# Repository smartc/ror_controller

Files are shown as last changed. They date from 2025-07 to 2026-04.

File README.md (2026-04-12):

# ESP32-S3 Roll-Off Roof Controller (v3)

ASCOM Alpaca compatible roll-off roof controller for remote observatory automation, built on ESP32-S3 with MQTT integration, weather safety interlock, and a browser-based control interface.





---

## SAFETY WARNING

**Relays on this board carry low-voltage control signals only.** They trigger external contactors -- never connect motors, inverters, or other high-current loads directly to the relay outputs. Use appropriately rated external contactors for all high-power switching.

---

## Features

### Roof Control
- Non-blocking state machine sequences relay operations without interrupting WiFi/MQTT
- Open, close, and stop via ASCOM, MQTT, or web interface
- Limit switch detection with configurable trigger state and swap option
- Two independent configurable timeouts: limit switch response (default 5s) and total movement (default 90s)

### Safety Interlocks
- **Park sensor**: blocks roof movement when telescope is unparked. Supports physical GPIO, UDP network sensors, or both (AND logic)
- **Weather/sky safety**: receives UDP broadcasts from safety sensor devices; blocks roof opening when any enabled sensor reports unsafe conditions. Fail-safe: an enabled sensor that goes offline is treated as unsafe
- **Auto-close**: optionally closes the roof automatically when weather becomes unsafe (requires telescope parked)
- All safety interlocks have bypass toggles accessible from both the Setup and Roof Control pages

### Inverter Control (v3 hardware)
- K1: 12V power relay (triggers external contactor)
- K3: Soft-power button relay (500ms pulse)
- AC power detection via optocoupler distinguishes relay state from actual inverter output
- Manual controls available from Roof Control page

### Web Interface
- Dark theme, responsive layout, 2-second live status polling
- Consistent navigation on all pages: Home, Roof Control, Setup, WiFi Config, Console, Update
- **Console page**: live ring-buffer debug log (50 entries), accessible remotely without serial monitor
- Park sensor and safety sensor management: per-sensor enable, bypass, and remove
- OTA firmware updates via ElegantOTA (auto-reboot after upload)

### MQTT / Home Assistant
- Publishes status every 30 seconds and on state change
- Accepts open/close/stop commands
- LWT availability topic
- Status payload includes weather safety state and safety bypass flag

### GPS / NTP / RTC
- Optional GPS module for time sync (configurable pins)
- DS3231 RTC backup (I2C)
- NTP server mode: serves time to local network devices
- PPS signal support for sub-second NTP accuracy
- Configurable timezone offset and DST

---

## Hardware (v3)

**Microcontroller**: ESP32-S3 44-pin  
**Power**: 12V DC input, onboard 5V regulator

### GPIO Assignments

| Pin | Function |
|-----|---|
| GPIO4 | K1 - Inverter power relay |
| GPIO5 | K2 - Roof button relay |
| GPIO6 | K3 - Inverter soft-power relay |
| GPIO7 | AC power detection (optocoupler) |
| GPIO8 | I2C SDA (RTC) |
| GPIO9 | I2C SCL (RTC) |
| GPIO35 | Open limit switch |
| GPIO36 | Closed limit switch |
| GPIO37 | Rain sensor (RG9) |
| GPIO38-41 | Snow sensor (digital + RS485) |
| GPIO42 | Physical park sensor |

GPS pins are configurable via the web interface (default TX: GPIO14).

---

## Installation

### Requirements

- Arduino IDE 2.0+
- Board: ESP32-S3 Dev Module
- Libraries (via Library Manager): ArduinoJson 6.x, PubSubClient, ElegantOTA

### Board Settings

| Setting | Value |
|---|---|
| USB CDC On Boot | Enabled |
| Flash Size | 4MB |
| Partition Scheme | Default 4MB with SPIFFS |
| Upload Speed | 921600 |
| USB Mode | Hardware CDC and JTAG |

### First Boot

1. Device starts in AP mode: SSID `RoofController`, password `RoofController`
2. Connect and open `http://192.168.4.1`
3. Enter WiFi credentials under WiFi Config
4. Device reboots and connects to your network

---

## Configuration

All settings are saved to NVS (survives reboots) and configurable via the web interface.

**Setup page** (`/setup`): pin assignments, trigger states, timeout values, MQTT broker, park sensor type, safety sensor enable/bypass, GPS/NTP settings, timezone

**WiFi Config** (`/wificonfig`): SSID and password

**Roof Control** (`/control`): park sensor bypass and safety sensor bypass toggles accessible here for quick override without navigating to setup

---

## MQTT

**Default topic prefix**: `observatory/roof`

| Topic | Direction | Description |
|---|---|---|
| `<prefix>/status` | Publish | JSON status (30s interval + on change) |
| `<prefix>/command` | Subscribe | `{"command":"open\|close\|stop"}` |
| `<prefix>/availability` | Publish | `online` / `offline` (LWT) |

### Status payload

```json
{
  "status": "Closed",
  "telescope_parked": true,
  "bypass_enabled": false,
  "weather_safe": true,
  "safety_bypass": false,
  "inverter_relay_state": false,
  "inverter_ac_power_state": false,
  "limit_open": false,
  "limit_closed": true,
  "device_id": "ESP32-XXXXXX",
  "ip_address": "192.168.1.100",
  "version": "3.3.0"
}
```

### Home Assistant example

```yaml
mqtt:
  cover:
    - name: "Observatory Roof"
      command_topic: "observatory/roof/command"
      state_topic: "observatory/roof/status"
      payload_open: '{"command":"open"}'
      payload_close: '{"command":"close"}'
      payload_stop: '{"command":"stop"}'
      value_template: "{{ value_json.status }}"
      state_open: "Open"
      state_closed: "Closed"
      availability_topic: "observatory/roof/availability"

  binary_sensor:
    - name: "Weather Safe"
      state_topic: "observatory/roof/status"
      value_template: "{{ value_json.weather_safe }}"
      payload_on: true
      payload_off: false
```

---

## ASCOM Alpaca

- Discovery: UDP port 32227, responds to `alpacadiscovery1`
- API base: `http://<device-ip>:11111/api/v1/dome/0/`
- Device type: Dome (RollOffRoof)

| Method | Description |
|---|---|
| `GET shutterstatus` | 0=Open, 1=Closed, 2=Opening, 3=Closing, 4=Error |
| `PUT openshutter` | Open roof (checks park + weather safety) |
| `PUT closeshutter` | Close roof |
| `PUT abortslew` | Stop movement |
| `GET athome` | True when closed |
| `GET atpark` | True when open |

---

## Web API

| Endpoint | Method | Description |
|---|---|---|
| `/` | GET | Home / status page |
| `/control` | GET | Roof control page |
| `/setup` | GET/POST | Configuration page |
| `/console` | GET | Debug log viewer |
| `/console.json` | GET | Raw log JSON |
| `/api/status` | GET | Live status JSON |
| `/open` | POST | Open roof |
| `/close` | POST | Close roof |
| `/stop` | POST | Stop movement |
| `/toggle_bypass` | POST | Toggle park sensor bypass |
| `/toggle_safety_bypass` | POST | Toggle safety sensor bypass |
| `/safety_sensor_enabled` | POST | Enable/disable a safety sensor |
| `/safety_sensor_bypass` | POST | Bypass a safety sensor |
| `/safety_sensor_remove` | POST | Remove a safety sensor |
| `/inverter_toggle` | POST | Toggle K1 power relay |
| `/inverter_button` | POST | K3 soft-power button press |
| `/update` | GET | OTA firmware update |
| `/restart` | POST | Reboot device |

---

## PCB Files

The `PCB Files/` directory contains v3.0 manufacturing files: schematic, layout, Gerbers, BOM, pick-and-place, and 3D model. Designed for JLCPCB, PCBWay, or equivalent.

---

## Changelog

### v3.3.0 (2026-04-12)
- Safety sensor integration: weather/sky condition interlock via UDP broadcasts
- Auto-close on unsafe weather (configurable, requires telescope parked)
- Safety sensor bypass controls on Setup and Roof Control pages
- Weather safe status and safety bypass state added to MQTT and `/api/status`
- Unified navigation bar across all pages with Console link
- Web-based debug console at `/console` (ring buffer, no serial monitor needed)
- Toggle switches replace checkboxes in safety sensor table
- Per-sensor remove and remove-all for both park and safety sensors
- Park sensor type saves immediately on selection (no Apply button)
- ElegantOTA auto-reboot fix
- HTML entity encoding for all non-ASCII characters

### v3.2.0 (2026-01-18)
- GPS/RTC/NTP support with PPS signal for sub-second accuracy
- DS3231 RTC backup with I2C detection
- NTP server mode for local network devices
- Timezone and DST configuration

### v3.0.0 (2026-01-11)
- Migrated to ESP32-S3 (44-pin)
- Triple relay system (K1, K2, K3)
- AC power detection via optocoupler
- Snow sensor input (digital + RS485)
- Dual inverter state tracking (relay vs AC power)
- Non-blocking roof state machine
- Dual movement timeout system

### v2.1.0
- Initial release: ESP32, ASCOM Alpaca, MQTT, UDP park sensors

---

## License

MIT License. See [LICENSE](LICENSE) for details.

**Author**: Corey Smart

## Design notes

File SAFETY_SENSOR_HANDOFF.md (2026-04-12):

# ROR Controller – Safety Sensor Integration Handoff

## Context

The SkyConditions_90640 device (ESP32-S3 ASCOM sky conditions sensor, separate project at
`../SkyConditions_90640`) has been updated to broadcast a UDP safety packet on the local
subnet using the Dark Dragon Astronomy park-sensor protocol. This document describes the
changes needed to the ROR controller to receive and act on those broadcasts.

The design should also accommodate **future distributed safety sensors** of the same type
(e.g. a standalone cloud sensor, an all-sky camera, a wind sensor) — any device that can
broadcast a `SafetySensor` UDP packet on the same port should be automatically discovered
and incorporated into the safety decision, using the same per-sensor enable/bypass model
that already exists for park sensors.

---

## What the SkyConditions device broadcasts

**UDP port:** 23435 (same port the ROR controller already listens on for park sensors)

**Interval:** Every 30 seconds by default; immediately on any wet ↔ dry state change.

**Packet format (JSON):**
```json
{
  "serialNumber": "a4cf1234abcd",
  "deviceType":   "SafetySensor",
  "name":         "Observatory Safety Sensor",
  "isSafe":       true,
  "rainState":    "dry",
  "ambTemp":      12.5
}
```

Key differences from park sensor packets:
- `deviceType` is `"SafetySensor"` (park sensors use `"ScopeParkSensor"` or similar)
- Safety state field is `"isSafe"` (park sensors use `"isSafeToMove"`)
- No `pitch` or `roll` fields
- Extra fields: `rainState` (`"wet"` or `"dry"`), `ambTemp` (°C, or JSON `null` before first sensor read)
- `serialNumber` is the device MAC address (hex, no colons) — stable and unique per device

**Current ROR behaviour:** The existing `processParkSensorMessage()` in `park_sensor_udp.cpp`
checks for the presence of `isSafeToMove` and silently drops any packet missing it, so
SafetySensor packets are already harmlessly ignored. Nothing is broken — this is purely additive.

---

## Changes required

### 1. Parse SafetySensor packets in `park_sensor_udp.cpp`

Add handling alongside the existing park sensor parser. When a packet arrives with
`deviceType == "SafetySensor"`:
- Read `isSafe` (bool) instead of `isSafeToMove`
- Store in a dedicated map keyed by `serialNumber`, separate from `discoveredSensors`
- Track `lastSeen` timestamp; mark offline after 90 seconds (3× the default broadcast interval)
- Log new discoveries and state changes; suppress repeated identical-state packets

Suggested data structure — mirrors the park sensor pattern closely for consistency:

```cpp
struct SafetySensor {
  String        serialNumber;
  String        name;
  String        ipAddress;
  bool          isSafe;
  float         ambTemp;         // NaN if JSON null was received
  unsigned long lastSeen;
  bool          online;          // false if timed out
  bool          enabled;         // user has opted this sensor into the safety decision
  bool          bypassEnabled;   // per-sensor bypass (excluded from safety check)
};

extern std::map<String, SafetySensor> discoveredSafetySensors;
```

### 2. Per-sensor enable and bypass — mirroring park sensor model

Each discovered SafetySensor should support:
- **Enabled** — user explicitly opts the sensor into the safety interlock. Newly discovered
  sensors default to **disabled** (discovered but not yet trusted) so an unexpected device
  on the network cannot silently gate the roof.
- **Bypass** — temporarily excludes an individual sensor from the safety decision without
  removing it. Useful for testing or known-bad sensor states.

Additionally, a **global safety sensor bypass** flag (`bypassSafetySensor`, default `false`)
overrides all sensors at once — the same pattern as `bypassParkSensor` for park sensors.
This is the testing / emergency override the user can toggle from the Setup or home page.

```cpp
bool bypassSafetySensor = false;   // global override — skips ALL safety sensor checks

// Returns true if weather is safe to open:
//   - global bypass enabled, OR
//   - no sensors are enabled, OR
//   - all enabled, non-bypassed, online sensors report isSafe=true
bool isWeatherSafe();
```

**`isWeatherSafe()` logic:**
```
if (bypassSafetySensor) return true;

hasActiveSensor = false
for each sensor in discoveredSafetySensors:
    if not sensor.enabled: continue
    if sensor.bypassEnabled: continue
    hasActiveSensor = true
    if not sensor.online: return false   // offline enabled sensor → fail-safe
    if not sensor.isSafe: return false

if not hasActiveSensor: return true      // no enabled sensors → don't block
return true
```

### 3. Gate roof OPENING on weather safety — do NOT gate closing

In `roof_controller.cpp`, the open safety check is around line 381.
Add a weather-safe interlock here:

```cpp
// === ROOF OPENING SAFETY CHECK ===
// Existing park sensor check ...
if (!bypassParkSensor && !telescopeParked) { return false; }

// NEW: weather safety — never open into rain/unsafe conditions
if (!isWeatherSafe()) {
    Debug.println("SAFETY CHECK FAILED: Weather unsafe");
    return false;
}
```

The closing check (around line 465) must **not** include a weather interlock —
rain is a reason to close, not a reason to refuse to close.

### 4. Auto-close on unsafe weather (optional, configurable)

Add a runtime-configurable NVS-backed setting:
- `weatherAutoClose` (bool, default: **false**)

When enabled, if `isWeatherSafe()` returns false AND the roof is currently open,
trigger a close command automatically.

**Critical safety requirement — check telescope park status before auto-closing:**

Auto-close must respect park sensor state including per-sensor bypass flags.
The existing `isTelescopeParked()` and `bypassParkSensor` already encapsulate this
correctly — use them directly:

```
if (weatherAutoClose && roofIsOpen && !isWeatherSafe()) {
    if (bypassParkSensor || isTelescopeParked()) {
        triggerClose("Auto-close: weather unsafe");
    } else {
        // Rain detected but telescope not confirmed parked — cannot safely close
        Debug.println("Auto-close SUPPRESSED: telescope not confirmed parked");
        // Surface a prominent warning in UI and MQTT
    }
}
```

Rain may be a cheaper problem than a smashed telescope. **Never auto-close if any
enabled, non-bypassed park sensor is offline, unparked, or in an unknown state.**

### 5. UI changes

**Setup page — new "Safety Sensors" section:**
- Table of all discovered SafetySensor devices (name, IP, serial, current state, last-seen)
- Per-sensor Enable checkbox and Bypass checkbox
- Global bypass toggle (`bypassSafetySensor`) with a clear warning label
- Toggle: "Auto-close on unsafe weather" (`weatherAutoClose`, default OFF)
  — display a warning that auto-close is suppressed if the telescope is not parked

**Home / status page:**
- Weather safety status badge: Safe / Unsafe / Bypassed / No sensor
- If auto-close is enabled and was suppressed by park sensor state, show a prominent alert

**MQTT:**
- Include `weather_safe: true/false` and `safety_bypass: true/false` in state payload
- Publish an event when auto-close is triggered or suppressed

---

## Extensibility — future safety sensors

The map-based design (`std::map<String, SafetySensor>`) naturally accommodates multiple
simultaneous devices. Any device on the same subnet that broadcasts a UDP packet with
`deviceType == "SafetySensor"` and `isSafe: true/false` will be automatically discovered
and appear in the UI for the user to enable. The `isWeatherSafe()` AND-logic then
incorporates all enabled, non-bypassed sensors.

Future sensor types that could use this same protocol:
- Standalone cloud/rain sensor
- Wind speed monitor
- All-sky camera safety output
- Generic "observatory is safe" relay device

No code changes are needed on the ROR controller to add new sensor instances — they
just need to broadcast the same JSON format.

---

## Relevant files to modify

| File | Changes needed |
|---|---|
| `park_sensor_udp.h/.cpp` | Add `SafetySensor` struct, map, parser, `isWeatherSafe()`, enable/bypass functions, NVS save/load |
| `roof_controller.cpp` | Weather interlock in open check (~line 381); auto-close logic in main loop |
| `roof_controller.h` | Expose `bypassSafetySensor`, `weatherAutoClose` |
| `config.h` | Add `SAFETY_SENSOR_TIMEOUT 90000` constant |
| `web_ui_handler.cpp` | POST handler for new settings |
| `html_templates.h` | Safety Sensors section on Setup page; status badge on home page |
| `mqtt_handler.cpp` | Publish `weather_safe` and `safety_bypass` in state payload |

Follow the existing NVS load/save pattern from `park_sensor_udp.cpp` for all new settings.

---

## Safety decision matrix

| Scenario | Open roof? | Close roof? | Auto-close? |
|---|---|---|---|
| Global safety bypass enabled | ✓ | ✓ | n/a |
| Weather safe, telescope parked | ✓ | ✓ | n/a |
| Weather safe, telescope unparked | ✗ | ✗ | n/a |
| Unsafe weather, telescope parked | ✗ | ✓ | ✓ if enabled |
| Unsafe weather, telescope unparked | ✗ | ✗ | ✗ suppressed |
| Unsafe weather, park sensor offline | ✗ | ✗ | ✗ suppressed |
| Unsafe weather, park sensor bypassed | ✗ | ✓ | ✓ if enabled |
| Safety sensor offline (was enabled) | ✗ | ✓ | ✓ if enabled + telescope parked |
| Safety sensor bypassed individually | ignored | ✓ | ✓ if enabled + telescope parked |
| No safety sensors enabled | ✓ | ✓ | n/a |

**Fail-safe principle:** an enabled safety sensor that goes offline should be treated as
unsafe for the purpose of the open interlock. The user can bypass it explicitly if they
know the sensor has failed and conditions are actually safe.

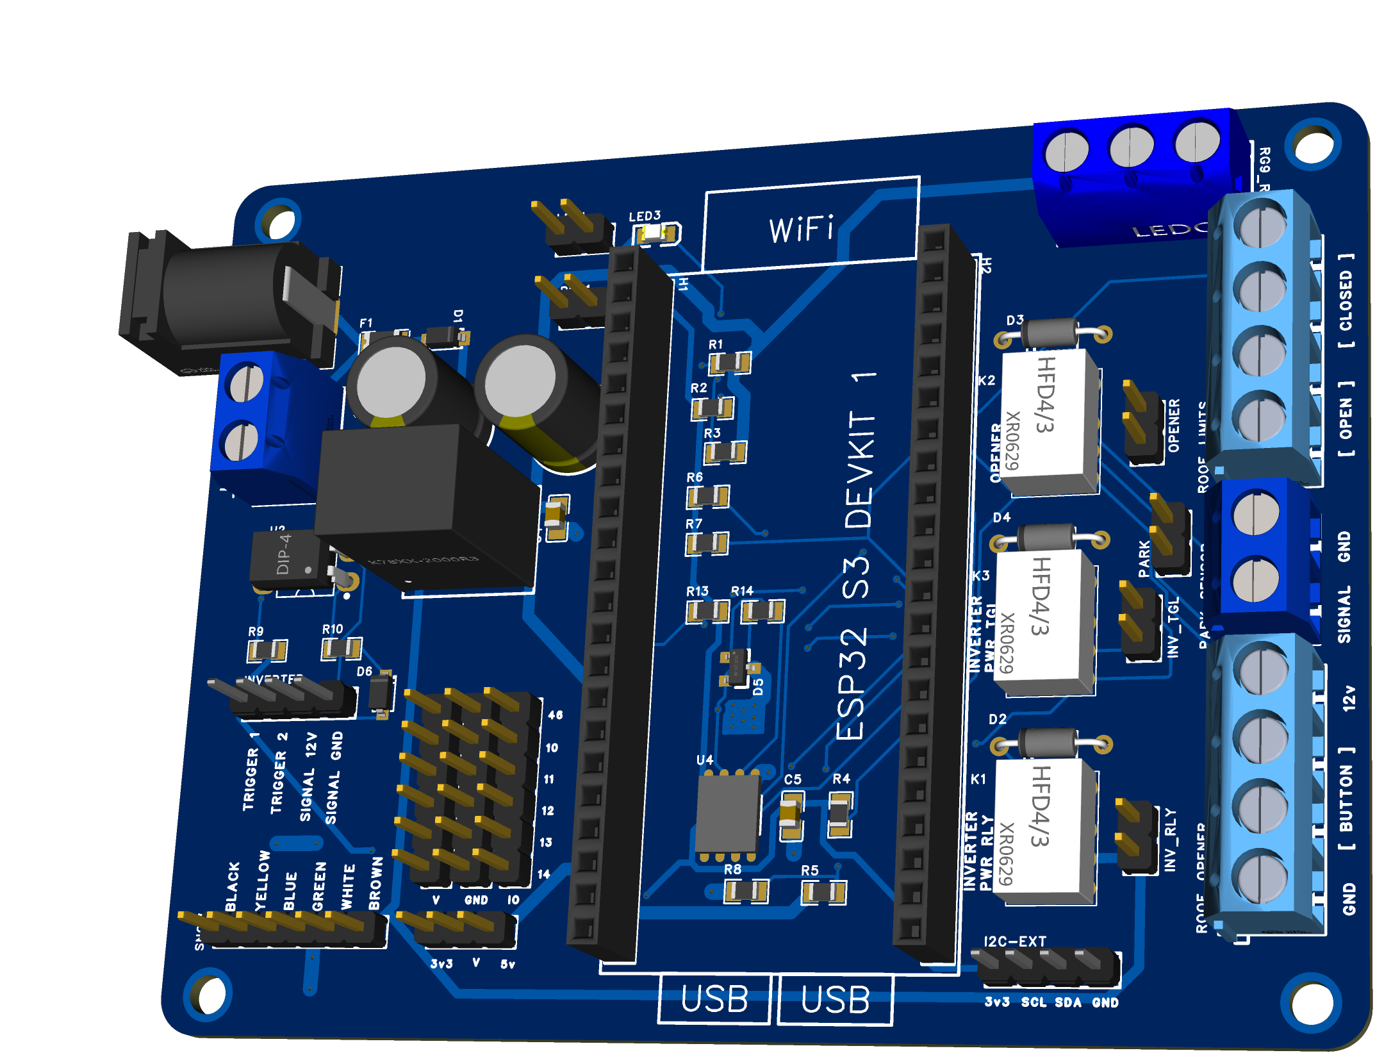
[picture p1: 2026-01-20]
PCB Files/3D_PCB_v3.1.png

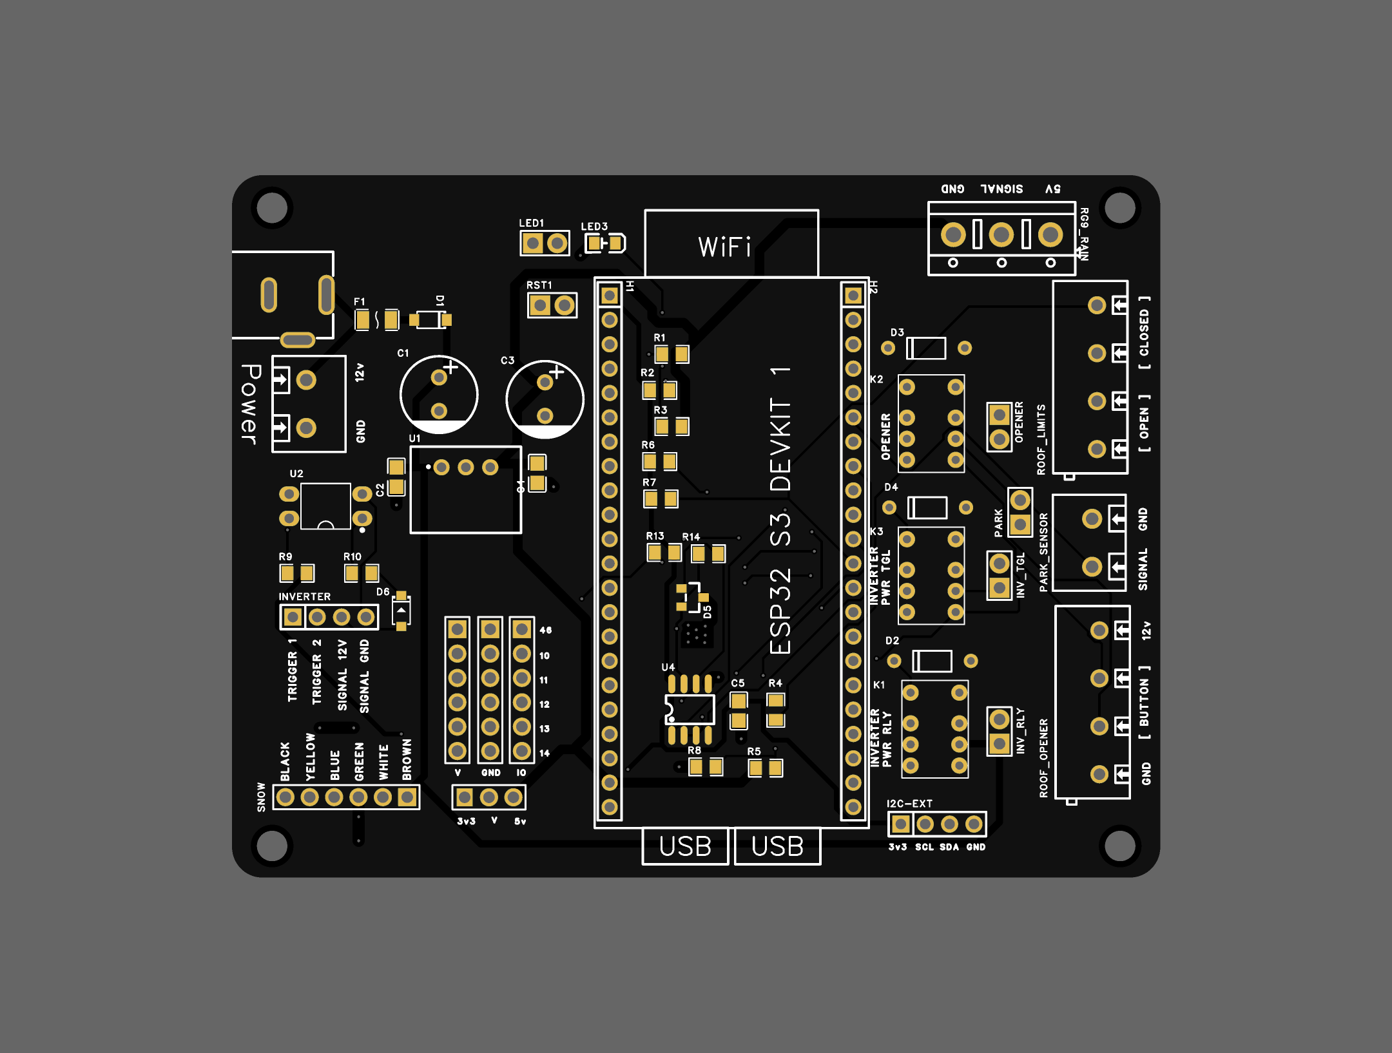
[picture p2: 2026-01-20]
PCB Files/2D_PCB_Top_v3.1.png

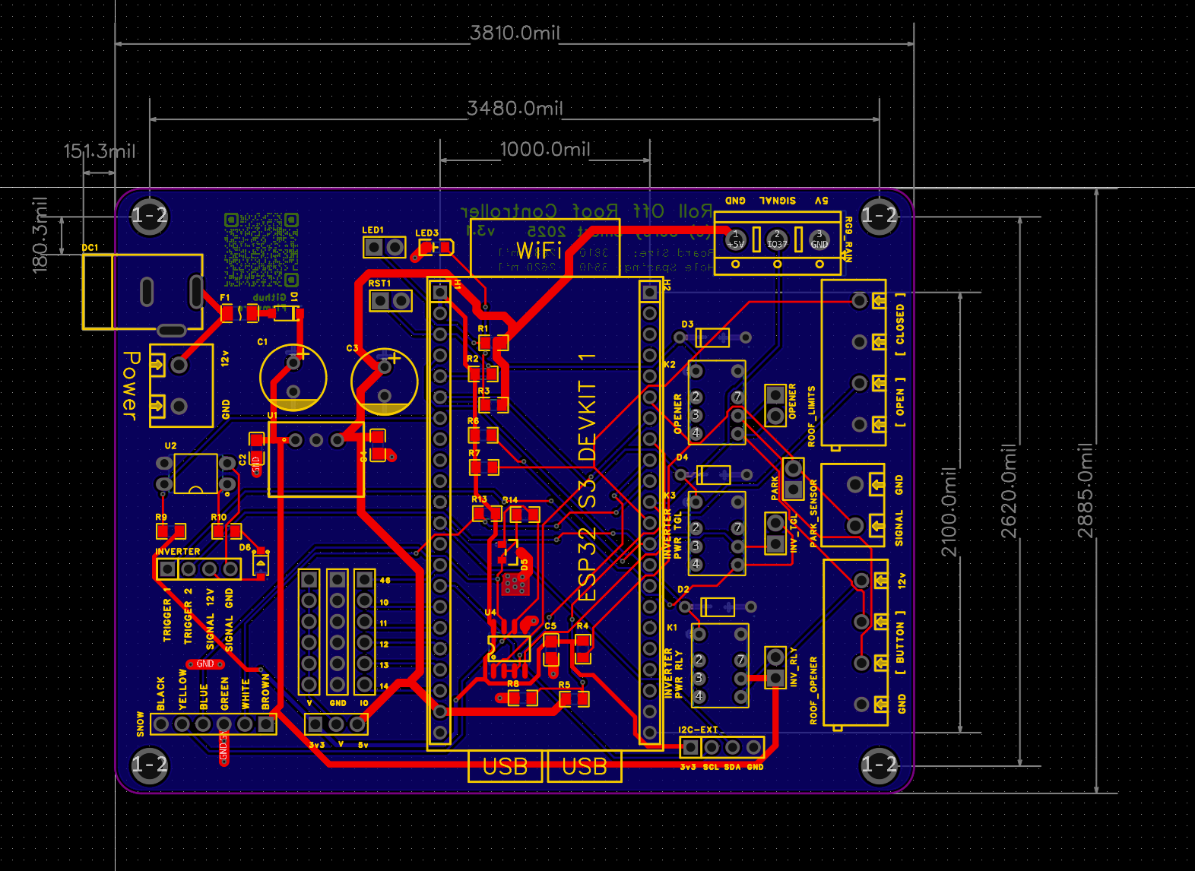
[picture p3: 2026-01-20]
PCB Files/PCB_Dimensions_v3.1.png

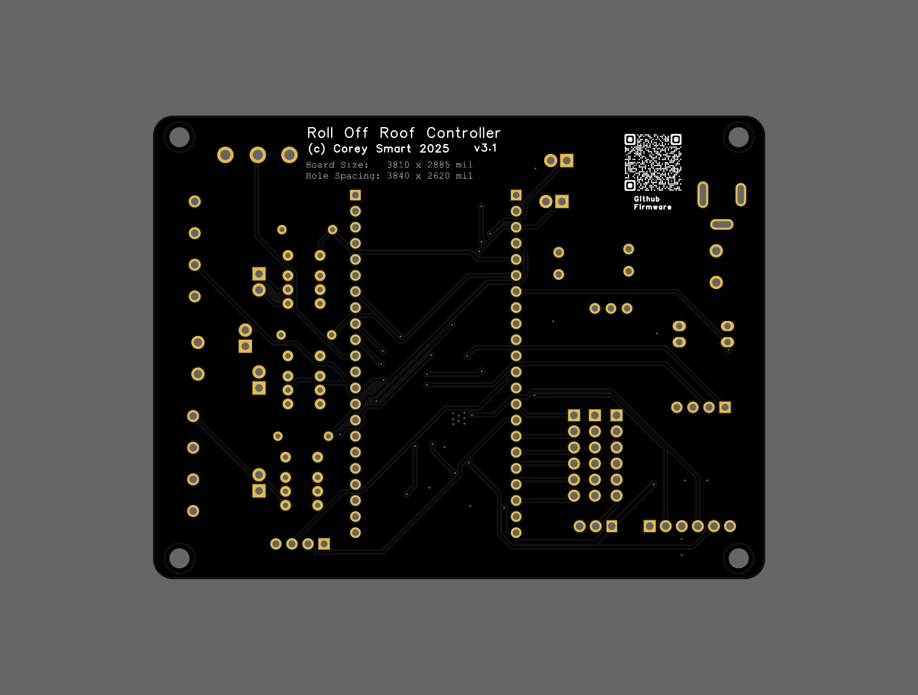
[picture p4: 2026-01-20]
PCB Files/2D_PCB_Bottom_v3.1.png

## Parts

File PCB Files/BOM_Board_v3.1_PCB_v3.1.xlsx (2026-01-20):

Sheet: bom模板
 |  |  |  | Bill of Materials | BOM_Board_v3.0_PCB_v3.0_2026-01-19
 |  |  |  | Project Title： | ESP32 ROR Controller (v3)
 |  |  |  | Variant:
 |  |  |  | Report Time： | 2026年1月19日 18:10:29
No. | Quantity | Comment | Designator | Footprint | Value | Manufacturer Part | Manufacturer | Supplier Part | Supplier | LCSC Price | Total
1 | 2 | 220uF | C1, C3 | CAP-TH_BD8.0-P3.50-D0.5-FD | 220uF | 220uF35V8x12KM | Econd(米朗电子) | C49304872 | LCSC |  | #VALUE!
2 | 1 | 10uF | C2 | C0805 | 10uF | C0805X106K010T | IHHEC(禾伸堂) | C340314 | LCSC |  | #VALUE!
3 | 1 | 22uF | C4 | C0805 | 22uF | CL21A226MAYNNNE | SAMSUNG(三星) | C602037 | LCSC |  | #VALUE!
4 | 1 | 100nF | C5 | C0805 | 100nF | C0805X104K101TB | IHHEC(禾伸堂) | C495959 | LCSC |  | #VALUE!
5 | 1 | DSK24 | D1 | SOD-123_L2.8-W1.8-LS3.7-RD |  | DSK24 | JUXING(钜兴) | C3033296 | LCSC |  | #VALUE!
6 | 3 | 1N4148 | D2, D3, D4 | DO-35_BD2.2-L4.0-D0.50_1N4148 |  | 1N4148 | LJ(朗捷) | C18195411 | LCSC |  | #VALUE!
7 | 1 | SM712 | D5 | SOT-23_L2.9-W1.3-P1.90-LS2.4-BR |  | SM712 | TDSEMIC(拓电半导体) | C46956321 | LCSC |  | #VALUE!
8 | 1 | 1N4148W | D6 | SOD-123_L2.7-W1.6-LS3.7-FD |  | 1N4148W | R+O(宏嘉诚) | C7420318 | LCSC |  | #VALUE!
9 | 1 | PJ-002A | DC1 | DC-IN-TH_PJ-002A |  | PJ-002A | CUI | C3096082 | LCSC |  | #VALUE!
10 | 1 | 0466002.NRHF | F1 | F1206 |  | 0466002.NRHF | Littelfuse(美国力特) | C3105 | LCSC |  | #VALUE!
11 | 2 | XY-PM254-1-22P-Z-8.5 | H1, H2 | HDR-TH_22P-P2.54-V-F |  | XY-PM254-1-22P-Z-8.5 | XYECONN(辛译) | C53200741 | LCSC |  | #VALUE!
12 | 4 | 2.54-1x6P直针 | H3, H4, H5, SNOW | HDR-TH_6P-P2.54-V-M-1 |  | 2.54-1x6P直针 | BOOMELE(博穆精密) | C37208 | LCSC |  | #VALUE!
13 | 1 | 2.54-1*3P针 | H6 | HDR-TH_3P-P2.54-V-M-1 |  | 2.54-1*3P针 | BOOMELE(博穆精密) | C49257 | LCSC |  | #VALUE!
14 | 2 | PZ254V-11-04P | I2C-EXT, INVERTER | HDR-TH_4P-P2.54-V-M |  | PZ254V-11-04P | XFCN(兴飞) | C492403 | LCSC |  | #VALUE!
15 | 6 | PZ254V-11-02P | INV_RLY, INV_TGL, LED1, OPENER, PARK, RST1 | HDR-TH_2P-P2.54-V-M |  | PZ254V-11-02P | XFCN(兴飞) | C492401 | LCSC |  | #VALUE!
16 | 3 | HFD4/3 | K1, K2, K3 | RELAY-TH_HFD4-3 |  | HFD4/3 | HF(宏发) | C119084 | LCSC |  | #VALUE!
17 | 1 | NCD0805R1 | LED3 | LED0805-RD |  | NCD0805R1 | 国星光电 | C84256 | LCSC |  | #VALUE!
18 | 2 | DB301V-5.0-2P-BU-S | PARK_SENSOR, PWR | CONN-TH_2P-P5.00_L7.6-W10.0 |  | DB301V-5.0-2P-BU-S | DORABO(地博电气) | C395882 | LCSC |  | #VALUE!
19 | 3 | 5.1kΩ | R1, R3, R5 | R0805 | 5.1kΩ | 0805W8F5101T5E | UNI-ROYAL(厚声) | C27834 | LCSC |  | #VALUE!
20 | 4 | 10kΩ | R2, R8, R9, R13 | R0805 | 10kΩ | 0805W8F1002T5E | UNI-ROYAL(厚声) | C17414 | LCSC |  | #VALUE!
21 | 3 | 47kΩ | R4, R6, R7 | R0805 | 47kΩ | 0805W8F4702T5E | UNI-ROYAL(厚声) | C17713 | LCSC |  | #VALUE!
22 | 1 | 1kΩ | R10 | R0805 | 1kΩ | CR0805J80102G | LIZ(丽智电子) | C101925 | LCSC |  | #VALUE!
23 | 1 | 120Ω | R14 | R0805 | 120Ω | 0805W8F1200T5E | UNI-ROYAL(厚声) | C17437 | LCSC |  | #VALUE!
24 | 1 | DB301V-5.0-3P-BU-P | RG9_RAIN | CONN-TH_3P-P5.00_DB301V-5.0-3P-BU-P |  | DB301V-5.0-3P-BU-P | DORABO(地博电气) | C430620 | LCSC |  | #VALUE!
25 | 2 | DB301V-5.0-4P-BU-S | ROOF_LIMITS, ROOF_OPENER | CONN-TH_4P-P5.00_DB301V-5.0-4P-BU-S |  | DB301V-5.0-4P-BU-S | DORABO(地博电气) | C3034542 | LCSC |  | #VALUE!
26 | 1 | K7805-2000R3 | U1 | PWRM-TH_K78XX-2000R3 |  | K7805-2000R3 | RLT(瑞率特) | C48888165 | LCSC |  | #VALUE!
27 | 1 | PC817C | U2 | DIP-4_L4.6-W6.5-P2.54-LS7.6-BL |  | PC817C | KTP(科泰普) | C20612449 | LCSC |  | #VALUE!
28 | 1 | MAX3485ED | U4 | SOP-8_L4.9-W3.9-P1.27-LS6.0-BL |  | MAX3485ED | HTC | C558792 | LCSC |  | #VALUE!
29 | #VALUE!

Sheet: Field汇总
Project Title | ESP32 ROR Controller (v3)
Borard Title | Board_v3.0
Schematic Title
PCB Title | PCB_v3.0
Variant Name
Total Quantity | 52
Report Time | 18:10:29
Report Date | 2026年1月19日
Report Date&Time | 2026年1月19日 18:10:29
File Name | BOM_Board_v3.0_PCB_v3.0_2026-01-19
Filter Option | Add into BOM:no;

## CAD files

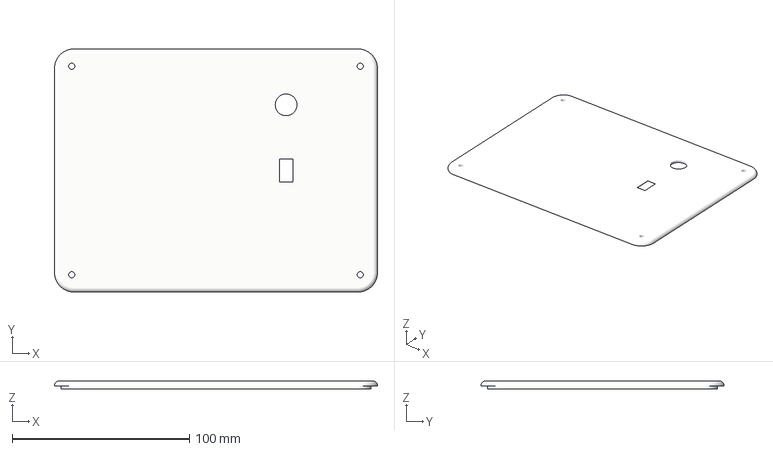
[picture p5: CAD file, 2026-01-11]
Housing/Lid.3mf
182.0 x 137.0 x 4.50 mm

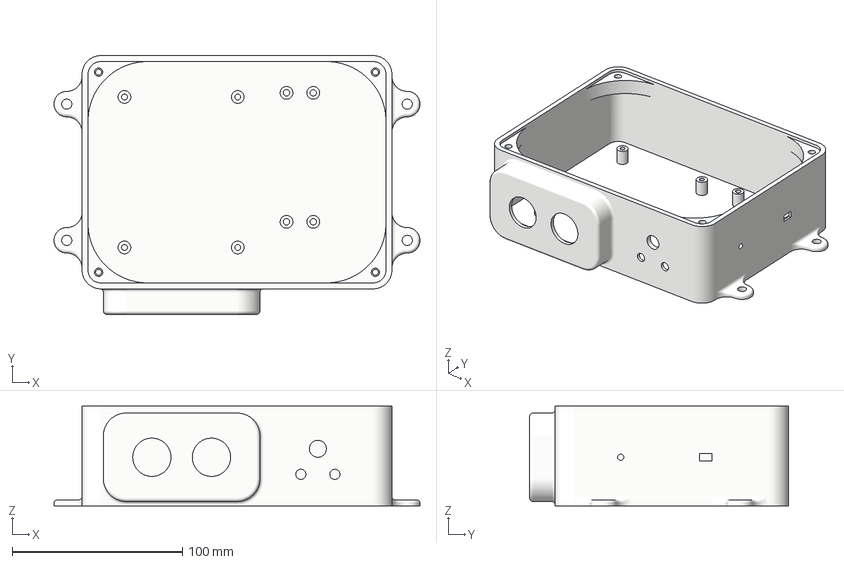
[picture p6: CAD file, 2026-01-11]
Housing/Housing Body.3mf
215.0 x 152.0 x 58.5 mm

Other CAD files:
Housing/ROR Controller Housing v3.f3d

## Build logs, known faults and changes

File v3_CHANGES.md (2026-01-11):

# ESP32-S3 Roll-Off Roof Controller v3 Hardware Changes

## Hardware Changes

### Microcontroller Upgrade
- **From:** ESP32 (standard variant)
- **To:** ESP32-S3 (44-pin variant)
- **Reason:** Improved availability, larger ROM size

### New GPIO Pin Assignments (ESP32-S3)
- **K1 (Inverter Power Relay):** GPIO4
- **K2 (Roof Opener Button Relay):** GPIO5
- **K3 (Inverter Soft-Power Button - NEW):** GPIO6
- **AC Power State Detection (NEW):** GPIO7
- **Open Limit Switch:** GPIO35
- **Closed Limit Switch:** GPIO36
- **Park Sensor:** GPIO42
- **RG9 Rain Sensor:** GPIO37
- **Snow Sensor (Digital - NEW):** GPIO38
- **Snow Sensor (RS485 RO):** GPIO41
- **Snow Sensor (RS485 RE/DE):** GPIO39
- **Snow Sensor (RS485 DI):** GPIO40

### New Relays
- **K1:** Inverter 12V power relay (existing functionality)
- **K2:** Roof opener button relay (existing functionality)
- **K3:** Inverter soft-power button relay (**NEW** - for inverters requiring button press to power on/off)

### New Sensors
- **AC Power Detection:** Optocoupler on GPIO7 detects when inverter AC power is ON
- **12V Snow/Rain Sensor:** Support for additional precipitation sensor (digital + RS485)

### Power Supply Improvements
- Larger input capacitors for better stability
- Upsized fuse for improved safety
- Different 5V regulator for enhanced reliability

## Software Changes

### Core Functionality
1. **Updated all pin definitions** to match ESP32-S3 GPIO assignments
2. **Added third relay control (K3)** for inverter soft-power button
3. **AC power state monitoring** via optocoupler
4. **Inverter power state tracking** (relay state + AC power state)

### New Functions (roof_controller.cpp)
- `toggleInverterPower()` - Toggle K1 inverter power relay
- `sendInverterButtonPress()` - Send K3 soft-power button press
- `getInverterRelayState()` - Get state of K1 relay
- `getInverterACPowerState()` - Get state of AC power
- `updateInverterPowerStatus()` - Monitor and update AC power state

### Web Interface Enhancements
- **New Inverter Control Card** displaying:
  - Power Relay (K1) state
  - AC Power state
- **Manual Control Buttons:**
  - Toggle Power Relay (K1)
  - Press Soft-Power Button (K3)
- Real-time status indicators with color coding

### MQTT Integration
New MQTT topics published in status messages:
- `inverter_relay_state` - Boolean (true/false)
- `inverter_ac_power_state` - Boolean (true/false)

### API Endpoints
New web API endpoints:
- `POST /inverter_toggle` - Toggle inverter power relay
- `POST /inverter_button` - Send soft-power button press
- `GET /inverter_status` - Get inverter power states (JSON)

## Compilation Settings

### ESP32-S3 Arduino IDE Settings
- **Board:** ESP32-S3 Dev Module
- **USB CDC On Boot:** Enabled
- **Flash Size:** 4MB (or larger)
- **Partition Scheme:** Default 4MB with SPIFFS
- **Upload Speed:** 921600
- **USB Mode:** Hardware CDC and JTAG

## Migration from v2 to v3

### Pin Remapping
If you have existing v2 hardware, note the following changes:
- All GPIO pins have changed due to ESP32-S3 architecture
- Update any external connections according to new schematic

### New Features
- Test the inverter soft-power button (K3) functionality
- Verify AC power detection via optocoupler
- Configure snow sensor if using additional precipitation detection

### Configuration Preservation
- All existing settings (WiFi, MQTT, etc.) are preserved in preferences
- Pin configurations may need to be reviewed in setup page

## Version Information
- **Hardware Version:** v3 (2026-01-07)
- **Firmware Version:** 3.0.0
- **Board:** ESP32-S3 44-pin
- **Compatible with:** ASCOM Alpaca protocol

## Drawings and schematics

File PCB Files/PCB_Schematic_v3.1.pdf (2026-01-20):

# NF NF

NF

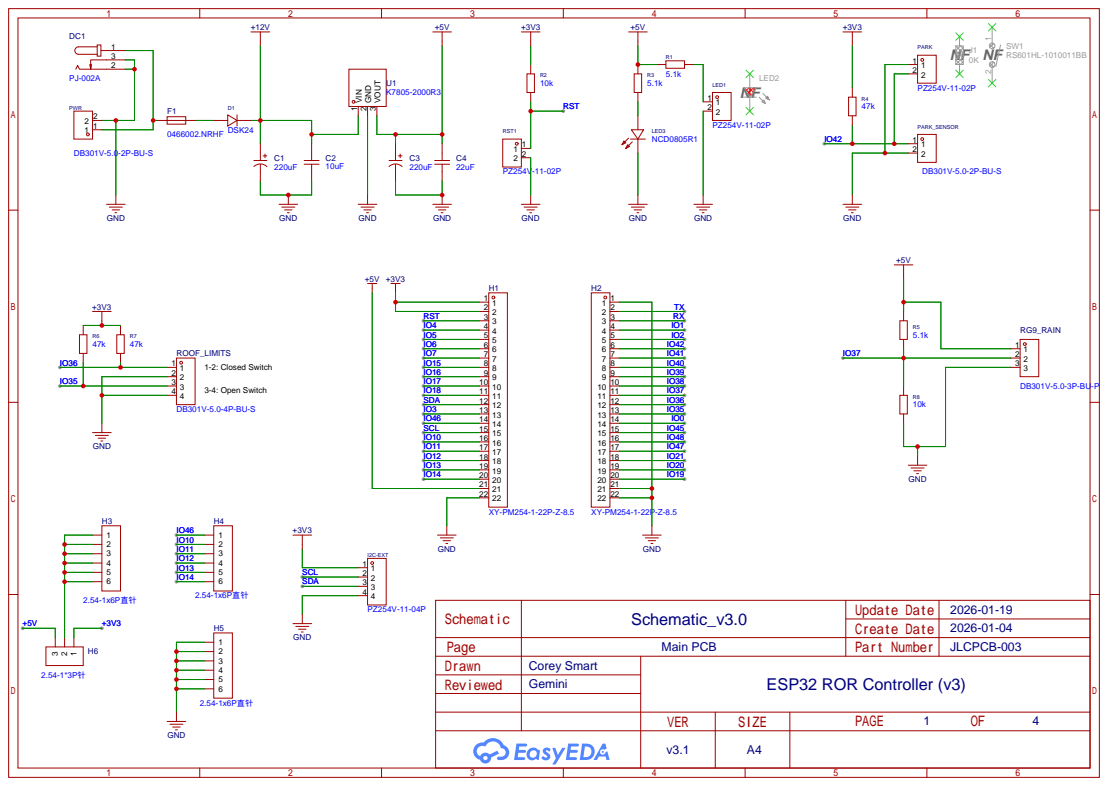
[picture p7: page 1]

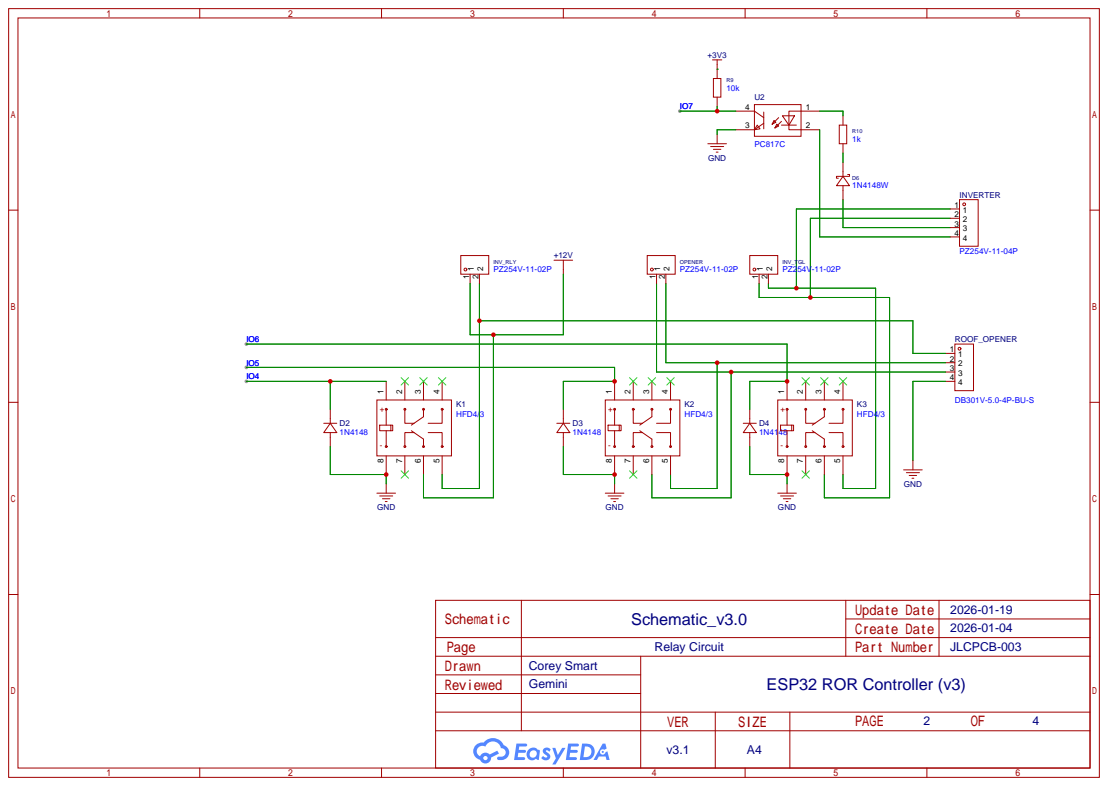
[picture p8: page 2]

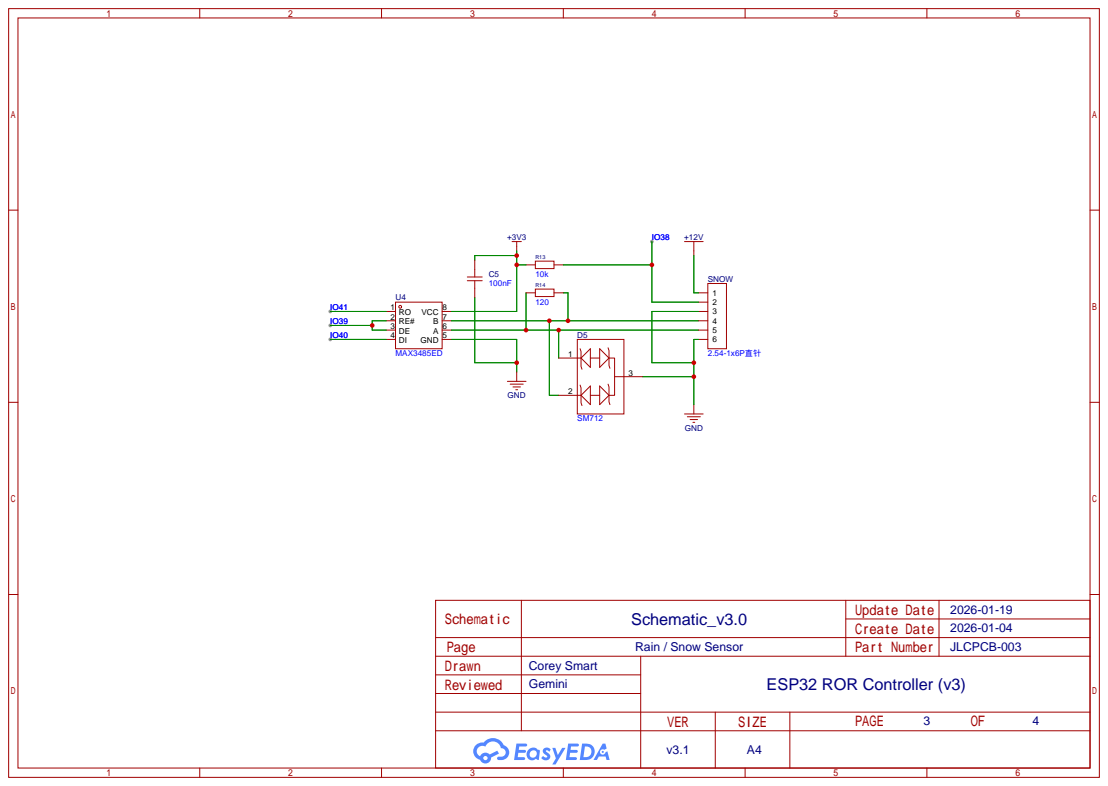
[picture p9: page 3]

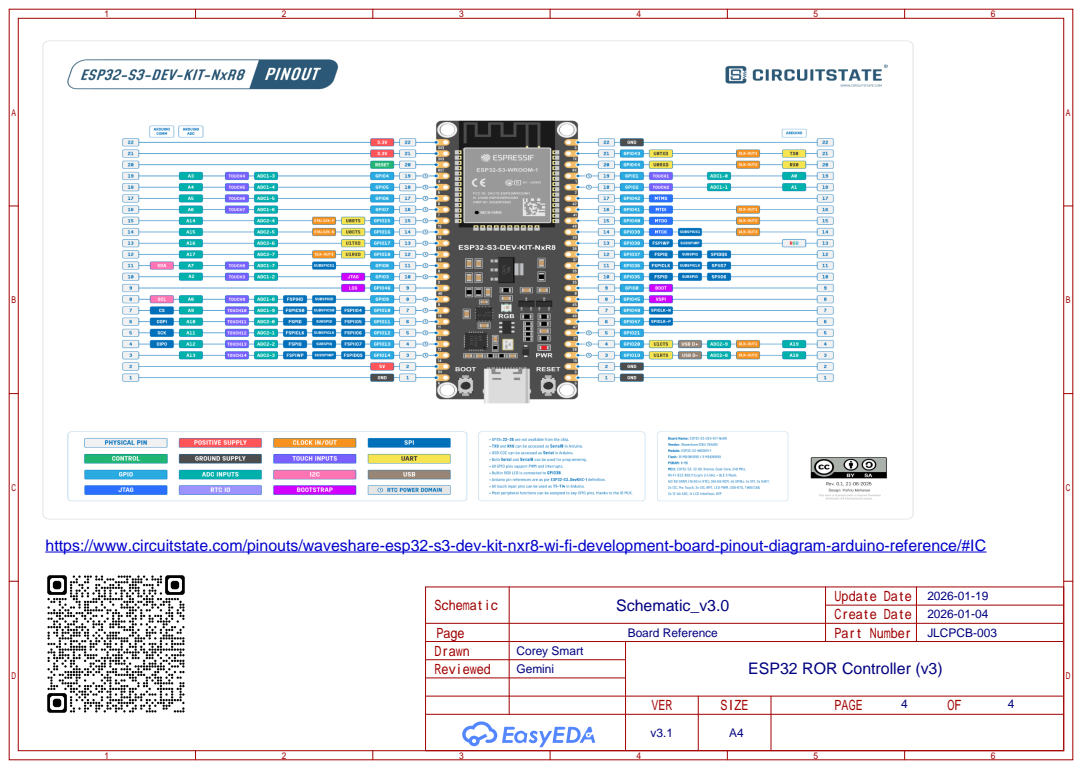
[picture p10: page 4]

https://www.circuitstate.com/pinouts/waveshare-esp32-s3-dev-kit-nxr8-wi-fi-development-board-pinout-diagram-arduino-reference/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

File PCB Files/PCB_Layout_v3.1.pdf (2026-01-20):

# WiFi

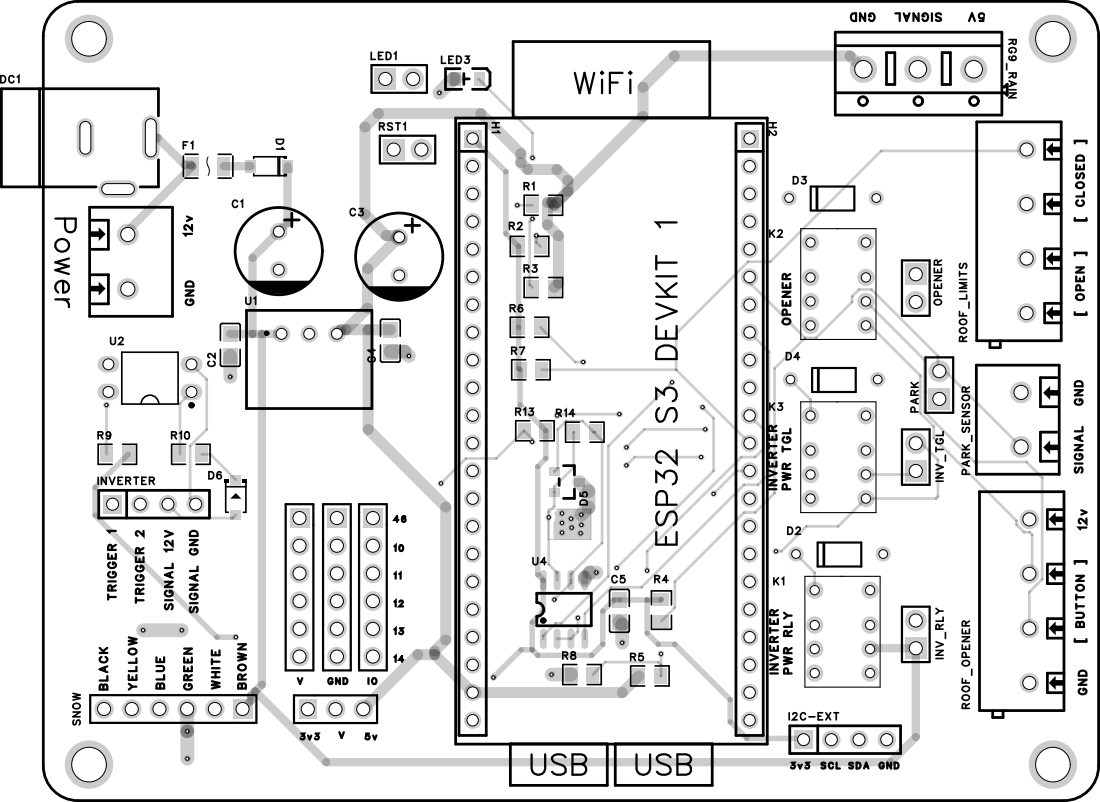
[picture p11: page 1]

GND 12v [ BUTTON ] [ OPEN ] [ CLOSED ]

# Roll Off Roof Controller

(c) Corey Smart 2025 | v3.1

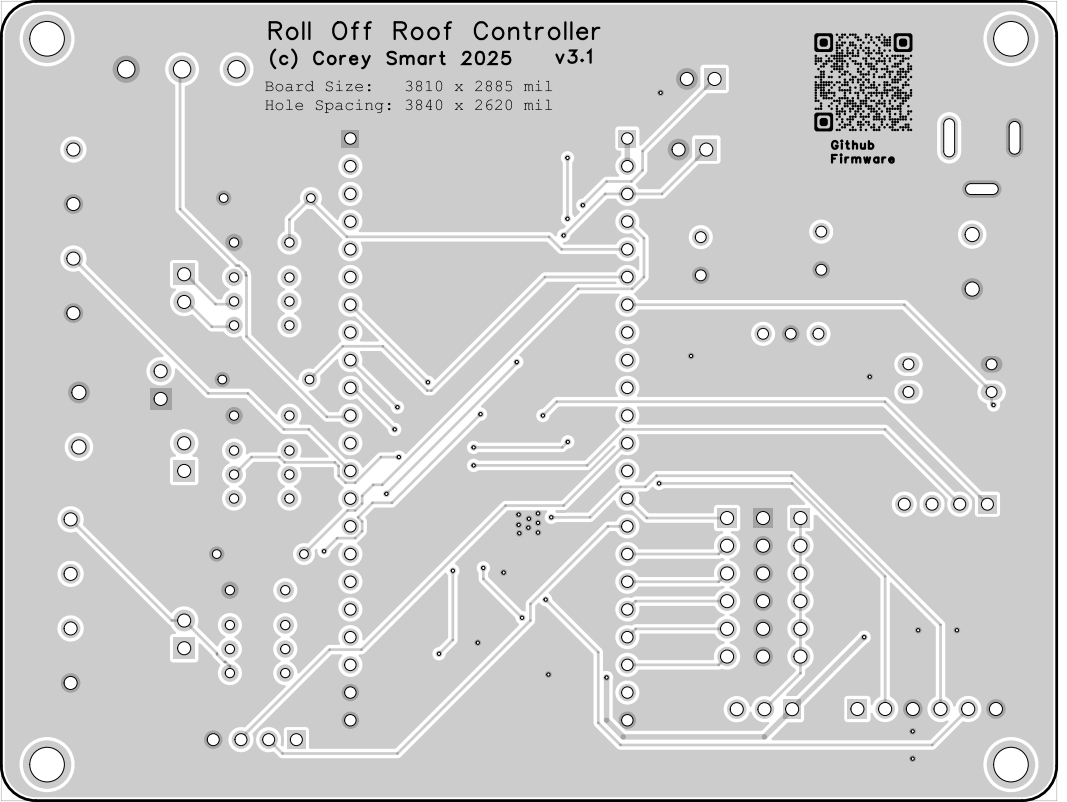
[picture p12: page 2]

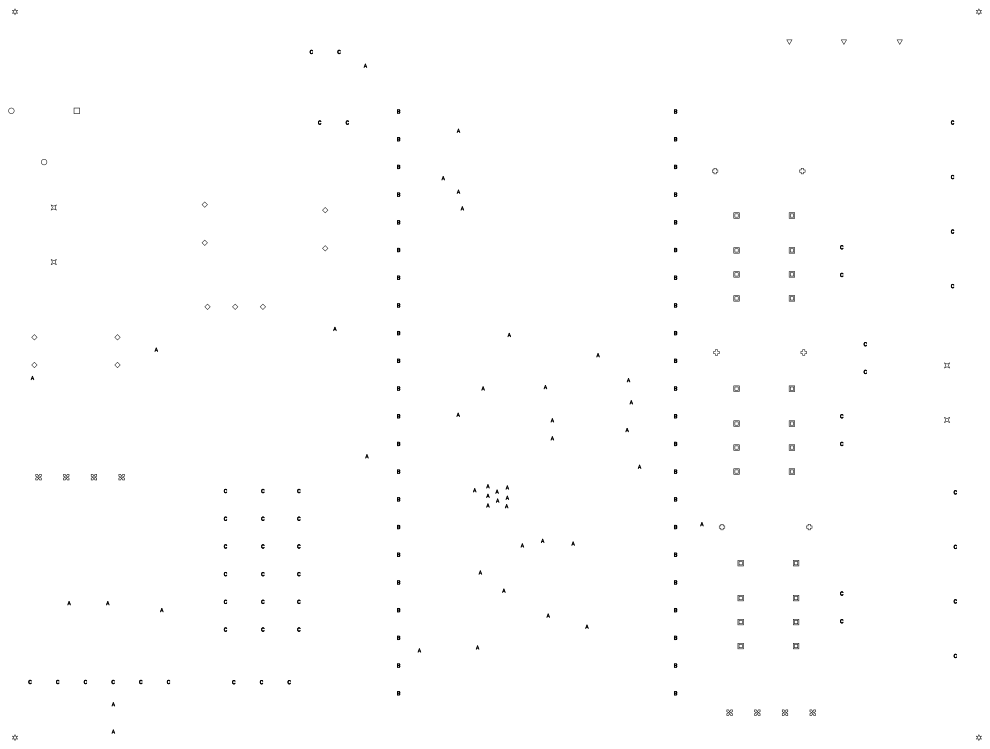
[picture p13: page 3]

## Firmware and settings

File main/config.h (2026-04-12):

/*
 * ESP32-S3 ASCOM Alpaca Roll-Off Roof Controller (v3)
 * Configuration Header File
 * Hardware: ESP32-S3 44-pin with 3 relays
 */

#ifndef CONFIG_H
#define CONFIG_H

#include <Arduino.h>  // Include Arduino.h to get LOW/HIGH and uint32_t definitions

// Debug level setting
#define DEBUG_LEVEL 1  // 0=Off, 1=Basic, 2=Verbose

// Brown-out detection setting
// Set to 1 to DISABLE brown-out detection (use if motor causes resets)
// WARNING: Disabling brown-out detection can cause data corruption if voltage drops too low
#define DISABLE_BROWNOUT_DETECTION 0

// Version Information
#define DEVICE_VERSION "3.4.0"  // v3.4: UI styling consistency with SkyConditions_90640 (navy theme, nav, setup page layout)
#define DEVICE_MANUFACTURER "Corey Smart"
#define DEVICE_NAME "ESP32-S3 Roll-Off Roof Controller (v3)"

// GPIO pin definitions for ESP32-S3 v3 Hardware
// Control Pins - Relays
const int INVERTER_PIN = 4;                 // K1: Inverter 12V power relay
const int ROOF_CONTROL_PIN = 5;             // K2: Roof opener button relay
const int INVERTER_BUTTON_PIN = 6;          // K3: Inverter soft-power button relay (NEW in v3)

// Input Pins - Status and Sensors
const int INVERTER_AC_POWER_PIN = 7;        // AC power state detection via optocoupler (NEW in v3)
const int TELESCOPE_PARKED_PIN = 42;        // Safety interlock on telescope park position
const int RAIN_SENSOR_PIN = 37;             // RG9 Rain sensor input

// Snow Sensor Pins (NEW in v3)
const int SNOW_SENSOR_DIGITAL_PIN = 38;     // 12V Snow sensor digital input
const int SNOW_SENSOR_RS485_RO = 41;        // RS485 RO (Receiver Output)
const int SNOW_SENSOR_RS485_RE_DE = 39;     // RS485 RE/DE (Receiver Enable / Driver Enable)
const int SNOW_SENSOR_RS485_DI = 40;        // RS485 DI (Driver Input)

// GPS Module Pins - configurable via WebUI
extern int gpsTxPin;                        // GPS TX -> ESP32 RX (receives GPS data)
extern int gpsRxPin;                        // GPS RX -> ESP32 TX (send commands to GPS, -1 to disable)
extern int gpsPpsPin;                       // GPS PPS pin for precise timing (-1 to disable)

// Default GPS Pin Settings
const int DEFAULT_GPS_TX_PIN = 14;          // Default: GPIO14
const int DEFAULT_GPS_RX_PIN = -1;          // Default: disabled (not needed for receive-only)
const int DEFAULT_GPS_PPS_PIN = -1;         // Default: disabled (not yet wired)

// I2C Pins for RTC (DS3231)
const int I2C_SDA_PIN = 8;                  // I2C SDA
const int I2C_SCL_PIN = 9;                  // I2C SCL
const uint8_t DS3231_ADDRESS = 0x68;        // DS3231 I2C address

// Sensor Pins - defined as extern, will be set at runtime based on preferences
extern int LIMIT_SWITCH_OPEN_PIN;           // Limit switch at roof open position
extern int LIMIT_SWITCH_CLOSED_PIN;         // Limit switch at roof closed position

// Default Pin Settings for ESP32-S3
const int DEFAULT_OPEN_SWITCH_PIN = 35;
const int DEFAULT_CLOSED_SWITCH_PIN = 36;

// Pin States
extern int TRIGGERED;                   // Define whether pin is HIGH or LOW when limit switch is triggered
extern int TELESCOPE_PARKED;            // Define whether pin is HIGH or LOW when telescope is parked
const int DEFAULT_TRIGGER_STATE = LOW;  // Default trigger state
const int DEFAULT_PARK_STATE = LOW;     // Default park sensor state (LOW = normally open switch, pulled low when parked)

// Timing Settings
const uint32_t DEBOUNCE_DELAY = 100;        // Debounce delay in ms
const unsigned long SWITCH_STABLE_TIME = 500; // Time in ms a switch must be stable
extern unsigned long movementTimeout;        // Roof movement timeout in ms (configurable)
const unsigned long DEFAULT_MOVEMENT_TIMEOUT = 90000; // Default: 90 seconds
extern bool movementTimeoutEnabled;          // Enable/disable movement timeout monitoring (configurable)
const bool DEFAULT_TIMEOUT_ENABLED = true;   // Default: enabled
extern unsigned long limitSwitchTimeout;     // Time to wait for limit switch state change after movement starts (configurable)
const unsigned long DEFAULT_LIMIT_SWITCH_TIMEOUT = 5000; // Default: 5 seconds
extern bool limitSwitchTimeoutEnabled;       // Enable/disable limit switch timeout monitoring (configurable)
const bool DEFAULT_LIMIT_SWITCH_TIMEOUT_ENABLED = true; // Default: enabled

// Inverter Timing Settings (NEW in v3)
extern unsigned long inverterDelay1;         // Delay between K1 relay and K3 soft-power button (ms)
extern unsigned long inverterDelay2;         // Delay between inverter power-on and K2 roof button (ms)
const unsigned long DEFAULT_INVERTER_DELAY1 = 750;   // Default: 750ms
const unsigned long DEFAULT_INVERTER_DELAY2 = 1500;  // Default: 1500ms

// Safety Settings
extern bool bypassParkSensor;           // Software bypass state for telescope park sensors
extern bool bypassSafetySensor;         // Global override for all weather/sky safety sensors
extern bool weatherAutoClose;           // Auto-close roof when weather is unsafe

// GPS and RTC Settings
extern bool gpsEnabled;                 // Enable/disable GPS module
extern bool gpsNtpEnabled;              // Enable/disable NTP server functionality
extern bool rtcPresent;                 // RTC hardware detected
extern bool timeSynced;                 // Time has been synced (from GPS or RTC)
extern int16_t timezoneOffset;          // Timezone offset in minutes from UTC
extern bool dstEnabled;                 // Daylight Saving Time enabled

// UDP Park Sensor Settings
#define PREF_PARK_SENSOR_TYPE "parkSensorType"
#define PREF_UDP_PARK_ENABLED "udpParkEnabled"

// Default WiFi credentials (will be overridden by stored settings if available)
#define DEFAULT_WIFI_SSID "YOUR_SSID"
#define DEFAULT_WIFI_PASSWORD "SU93R53CR3tP@55w0Rd"

// AP Mode SSID and password
#define AP_SSID "RoofController"
#define AP_PASSWORD "RoofController"
#define AP_TIMEOUT 300000               // 5 minutes in milliseconds

// Default MQTT Configuration
#define PREF_MQTT_ENABLED "mqttEnabled"
#define DEFAULT_MQTT_SERVER "192.168.2.235"
#define DEFAULT_MQTT_PORT 1883
#define DEFAULT_MQTT_USER "mqtt_username"
#define DEFAULT_MQTT_PASSWORD "MQTT_P@55w0rd"
#define DEFAULT_MQTT_CLIENT_ID "RollOffRoof"
#define DEFAULT_MQTT_TOPIC_PREFIX "observatory/roof"
#define DEFAULT_MQTT_KEEPALIVE 60       // 60 seconds - broker waits ~1.5x before triggering LWT
#define MQTT_PUBLISH_INTERVAL 30000     // 30 seconds

// ASCOM Alpaca Configuration
const int ALPACA_PORT = 11111;
const int WEB_UI_PORT = 80;
const int ALPACA_DISCOVERY_PORT = 32227;
inline const char* ALPACA_DISCOVERY_MESSAGE = "alpacadiscovery1";

// Buffer sizes
#define SSID_SIZE 32
#define PASSWORD_SIZE 64
#define MQTT_SERVER_SIZE 64
#define MQTT_USER_SIZE 32
#define MQTT_PASSWORD_SIZE 64
#define MQTT_CLIENTID_SIZE 32
#define MQTT_TOPIC_SIZE 64

// Preferences namespace and keys
#define PREFERENCES_NAMESPACE "roofConfig"
#define PREF_TRIGGER_STATE "triggerState"
#define PREF_PARK_STATE "parkState"
#define PREF_SWAP_SWITCHES "swapSwitches"
#define PREF_BYPASS_SENSOR "bypassParkSensor"
#define PREF_MOVEMENT_TIMEOUT "moveTimeout"
#define PREF_TIMEOUT_ENABLED "timeoutEnabled"
#define PREF_LIMIT_SWITCH_TIMEOUT "limitSwitchTimeout"
#define PREF_LIMIT_SWITCH_TIMEOUT_ENABLED "limitSwitchTimeoutEn"
#define PREF_WIFI_SSID "ssid"
#define PREF_WIFI_PASSWORD "wifiPassword"
#define PREF_MQTT_SERVER "mqttServer"
#define PREF_MQTT_PORT "mqttPort"
#define PREF_MQTT_USER "mqttUser"
#define PREF_MQTT_PASSWORD "mqttPassword"
#define PREF_MQTT_CLIENT_ID "mqttClientId"
#define PREF_MQTT_TOPIC_PREFIX "mqttTopicPrefix"
#define PREF_MQTT_KEEPALIVE "mqttKeepalive"
#define PREF_INVERTER_RELAY_ENABLED "inverterRelayEn"
#define PREF_INVERTER_SOFTPWR_ENABLED "inverterSoftEn"
#define PREF_INVERTER_DELAY1 "inverterDelay1"
#define PREF_INVERTER_DELAY2 "inverterDelay2"

// GPS and RTC Configuration
#define PREF_GPS_ENABLED "gpsEnabled"
#define PREF_GPS_NTP_ENABLED "gpsNtpEnabled"
#define PREF_GPS_TX_PIN "gpsTxPin"
#define PREF_GPS_RX_PIN "gpsRxPin"
#define PREF_GPS_PPS_PIN "gpsPpsPin"
#define PREF_TIMEZONE_OFFSET "tzOffset"
#define PREF_DST_ENABLED "dstEnabled"
const int NTP_PORT = 123;                   // Standard NTP port
const int16_t DEFAULT_TIMEZONE_OFFSET = 0;  // Default: UTC (0 minutes)
const bool DEFAULT_DST_ENABLED = false;     // Default: DST disabled
// NTP server runs independently once time is synced from GPS or RTC
// PPS (Pulse Per Second) provides sub-second accuracy when GPS PPS pin is configured

// Enum for roof status - matches ASCOM ShutterStatus values
enum RoofStatus {
  ROOF_OPEN = 0,       // ShutterStatus.shutterOpen
  ROOF_CLOSED = 1,     // ShutterStatus.shutterClosed
  ROOF_OPENING = 2,    // ShutterStatus.shutterOpening
  ROOF_CLOSING = 3,    // ShutterStatus.shutterClosing
  ROOF_ERROR = 4       // ShutterStatus.shutterError
};

#endif // CONFIG_H

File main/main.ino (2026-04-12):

/*
 * ESP32-S3 ASCOM Alpaca Roll-Off Roof Controller (v3)
 *
 * This firmware implements an ASCOM Alpaca compatible Roll-Off Roof controller
 * using the ESP32-S3 microcontroller. It implements the ASCOM Dome interface
 * for controlling the roof movement. It also provides MQTT integration for
 * Home Assistant.
 *
 * HARDWARE: v3 (2026-01-07) - ESP32-S3 44-pin with 3 relays
 *        - K1: Inverter 12V power relay (GPIO4)
 *        - K2: Roof opener button relay (GPIO5)
 *        - K3: Inverter soft-power button relay (GPIO6) - NEW
 *        - AC Power Detection via optocoupler (GPIO7) - NEW
 *        - Support for 12V snow/rain sensor - NEW
 *
 * COMPILE SETTINGS for ESP32-S3:
 *        - Board: ESP32-S3 Dev Module
 *        - USB CDC On Boot: Enabled
 *        - Flash Size: 4MB (or larger)
 *        - Partition Scheme: Default 4MB with SPIFFS
 *        - Upload Speed: 921600
 *        - USB Mode: Hardware CDC and JTAG
 *
 */

#include <WiFi.h>
#include <ESPmDNS.h>
#include <ArduinoJson.h>
#include <Preferences.h>

// Project includes
#include "config.h"
#include "src/debug/Debug.h"
#include "src/roof/roof_controller.h"
#include "src/alpaca/alpaca_handler.h"
#include "src/mqtt/mqtt_handler.h"
#include "src/webserver/web_ui_handler.h"
#include "src/sensors/park_sensor_udp.h"
#include "src/safety/safety_sensor.h"
#include "src/sensors/gps_handler.h"

// For reset reason detection
#include "esp_system.h"
#include "soc/rtc_cntl_reg.h"

// WiFi credentials and configuration
char ssid[SSID_SIZE] = DEFAULT_WIFI_SSID;
char password[PASSWORD_SIZE] = DEFAULT_WIFI_PASSWORD;
bool apMode = false;
unsigned long apStartTime = 0;

// Timing variables
unsigned long lastMqttReconnectAttempt = 0;
unsigned long lastMqttPublish = 0;
unsigned long lastStatusUpdate = 0;

// Reset diagnostics (accessible from web UI)
String lastResetReason = "Unknown";
uint32_t rebootCount = 0;

// Get human-readable reset reason
String getResetReasonString() {
  esp_reset_reason_t reason = esp_reset_reason();
  switch (reason) {
    case ESP_RST_POWERON:   return "Power-on reset";
    case ESP_RST_EXT:       return "External reset (pin)";
    case ESP_RST_SW:        return "Software reset";
    case ESP_RST_PANIC:     return "Exception/panic reset";
    case ESP_RST_INT_WDT:   return "Interrupt watchdog reset";
    case ESP_RST_TASK_WDT:  return "Task watchdog reset";
    case ESP_RST_WDT:       return "Other watchdog reset";
    case ESP_RST_DEEPSLEEP: return "Deep sleep wake";
    case ESP_RST_BROWNOUT:  return "BROWNOUT RESET";  // <-- This is what we're looking for
    case ESP_RST_SDIO:      return "SDIO reset";
    default:                return "Unknown reset (" + String(reason) + ")";
  }
}

void setup() {
  // Initialize debug output
  Debug.begin(115200);

  // Optionally disable brown-out detection (if motor causes voltage drops)
  #if DISABLE_BROWNOUT_DETECTION
    WRITE_PERI_REG(RTC_CNTL_BROWN_OUT_REG, 0);
    Debug.println("WARNING: Brown-out detection DISABLED");
  #endif

  // Print reset reason FIRST - critical for diagnosing reboots
  lastResetReason = getResetReasonString();
  Debug.println("\n\n========================================");
  Debug.println("RESET REASON: " + lastResetReason);
  Debug.println("========================================\n");

  // Load and increment reboot counter from preferences
  Preferences bootPrefs;
  bootPrefs.begin("bootDiag", false);
  rebootCount = bootPrefs.getULong("rebootCount", 0) + 1;
  bootPrefs.putULong("rebootCount", rebootCount);
  bootPrefs.putString("lastReset", lastResetReason);
  bootPrefs.end();
  Debug.printf("Reboot count: %lu\n", rebootCount);

  // If brown-out detected, log a warning
  if (esp_reset_reason() == ESP_RST_BROWNOUT) {
    Debug.println("WARNING: Brown-out detected! Check power supply.");
    Debug.println("The motor may be causing voltage drops.");
    Debug.println("Consider setting DISABLE_BROWNOUT_DETECTION=1 in config.h");
  }

  Debug.println("ESP32-S3 ASCOM Alpaca Roll-Off Roof Controller (v3)");
  Debug.println("Version: " + String(DEVICE_VERSION));
  Debug.println("Manufacturer: " + String(DEVICE_MANUFACTURER));
  
  // Load configuration from preferences
  loadConfiguration();
  
  // Initialize roof controller hardware
  initializeRoofController();

  // Initialize RTC (DS3231) - do this early to have time available
  initRTC();

  // Initialize WiFi
  initWiFi();
  
  // Initialize UDP park sensor listener
  initParkSensorUDP();

  // Load safety sensor configuration (per-sensor enable/bypass, global bypass, auto-close)
  loadSafetySensorConfiguration();
  
  // Initialize MQTT if enabled
  if (mqttEnabled) {
    setupMQTT();
  } else {
    Debug.println("MQTT is disabled");
  }
  
  // Initialize Alpaca API
  setupAlpacaAPI();

  // Initialize Web UI
  initWebUI();

  // Initialize GPS if enabled
  if (gpsEnabled) {
    initGPS();
  } else {
    Debug.println("GPS is disabled");
  }

  // Initialize NTP server if enabled (works with GPS or RTC time)
  if (gpsNtpEnabled) {
    initNTP();
  }

  Debug.println("Setup complete!");
  Debug.printf("Free heap: %d bytes\n", ESP.getFreeHeap());
}

void loop() {
  unsigned long currentTime = millis();
  
  // Handle WiFi connection
  handleWiFi();
  
  // Handle UDP park sensor messages
  handleParkSensorUDP();

  // Process non-blocking roof operations (state machine)
  // This handles relay timing without blocking WiFi/MQTT
  processRoofOperation();

  // Update roof status
  updateRoofStatus();

  // Update telescope park status
  updateTelescopeStatus();

  // Update inverter power status (NEW in v3)
  updateInverterPowerStatus();

  // Check for movement timeout
  checkMovementTimeout();

  // Auto-close roof if weather becomes unsafe (no-op unless weatherAutoClose is enabled)
  checkWeatherAutoClose();
  
  // Handle Alpaca discovery
  handleAlpacaDiscovery();

  // Handle Alpaca endpoint requests
  alpacaServer.handleClient();
  
  // Handle MQTT
  if (mqttEnabled) {
    if (!mqttClient.connected()) {
      if (currentTime - lastMqttReconnectAttempt > 5000) {
        lastMqttReconnectAttempt = currentTime;
        reconnectMQTT();
      }
    } else {
      mqttClient.loop();
      
      // Publish status periodically
      if (currentTime - lastMqttPublish > MQTT_PUBLISH_INTERVAL) {
        publishStatusToMQTT();
        lastMqttPublish = currentTime;
      }
    }
  }
  
  // Handle web UI requests
  handleWebUI();

  // Required by ElegantOTA v3 to trigger reboot after successful upload
  ElegantOTA.loop();

  // Handle GPS data
  if (gpsEnabled) {
    handleGPS();
  }

  // Handle NTP server (independent of GPS - uses GPS or RTC time)
  handleNTP();

  // Clear timed out park sensors periodically (every 5 minutes)
  static unsigned long lastSensorCleanup = 0;
  if (currentTime - lastSensorCleanup > 300000) {
    clearTimeoutSensors();
    lastSensorCleanup = currentTime;
  }
  
  // Periodic status update (every 30 seconds)
  if (currentTime - lastStatusUpdate > 30000) {
    Debug.printf(2, "Status: Roof=%s, Telescope=%s, WiFi=%s, MQTT=%s, Heap=%d\n",
                 getRoofStatusString().c_str(),
                 telescopeParked ? "Parked" : "Unparked",
                 WiFi.status() == WL_CONNECTED ? "Connected" : "Disconnected",
                 mqttClient.connected() ? "Connected" : "Disconnected",
                 ESP.getFreeHeap());
    // Time source status
    TimeSource ts = getTimeSource();
    Debug.printf(2, "Time: %s %s UTC (Source: %s, RTC: %s)\n",
                 getDateString().c_str(),
                 getTimeString().c_str(),
                 ts == TIME_SOURCE_GPS ? "GPS" : (ts == TIME_SOURCE_RTC ? "RTC" : "None"),
                 isRTCPresent() ? "Present" : "Not found");
    Debug.printf(2, "Local: %s %s (TZ: %+d min, DST: %s)\n",
                 getLocalDateString().c_str(),
                 getLocalTimeString().c_str(),
                 timezoneOffset,
                 dstEnabled ? "On" : "Off");
    if (gpsEnabled) {
      GPSStatus gpsStatusData = getGPSStatus();
      Debug.printf(2, "GPS: Fix=%s, Sats=%d, Lat=%.6f, Lon=%.6f\n",
                   gpsStatusData.hasFix ? "Yes" : "No",
                   gpsStatusData.satellites,
                   gpsStatusData.latitude,
                   gpsStatusData.longitude);
    }
    lastStatusUpdate = currentTime;
  }
  
  // Small delay to prevent watchdog issues
  delay(10);
}

// Initialize WiFi connection
void initWiFi() {
  Debug.println("Initializing WiFi...");

  // Clean up any existing WiFi state
  WiFi.disconnect(true);  // Disconnect and clear stored credentials
  WiFi.softAPdisconnect(true);  // Stop any running AP
  delay(100);  // Allow cleanup to complete

  // Check if we have credentials to connect with
  if (strlen(ssid) > 0 && strcmp(ssid, "YOUR_SSID") != 0) {
    Debug.printf("Connecting to WiFi network: %s\n", ssid);
    
    // Disable Power Saving Mode -- Troubleshooting device disconnects
    WiFi.setSleep(WIFI_PS_NONE);
    
    // Set WiFi mode to station
    WiFi.mode(WIFI_STA);
    delay(100);

    WiFi.begin(ssid, password);

    // Wait up to 30 seconds for connection
    int attempts = 0;
    while (WiFi.status() != WL_CONNECTED && attempts < 60) {
      delay(500);
      Debug.print(".");
      attempts++;
    }
    Debug.println("");

    if (WiFi.status() == WL_CONNECTED) {
      Debug.println("WiFi connected successfully!");
      Debug.printf("IP address: %s\n", WiFi.localIP().toString().c_str());
      Debug.printf("Signal strength: %d dBm\n", WiFi.RSSI());
      apMode = false;
    } else {
      Debug.printf("Failed to connect to WiFi (status: %d), starting AP mode\n", WiFi.status());
      startAPMode();
    }
  } else {
    Debug.println("No valid WiFi credentials configured, starting AP mode");
    startAPMode();
  }
}

// Start Access Point mode for configuration
void startAPMode() {
  Debug.println("Starting AP mode...");

  // Clean up WiFi state before starting AP
  WiFi.disconnect(true);
  delay(100);

  // Set WiFi mode to AP
  WiFi.mode(WIFI_AP);
  delay(100);

  if (WiFi.softAP(AP_SSID, AP_PASSWORD)) {
    Debug.printf("AP mode started - SSID: %s, Password: %s\n", AP_SSID, AP_PASSWORD);
    Debug.printf("AP IP address: %s\n", WiFi.softAPIP().toString().c_str());
    apMode = true;
    apStartTime = millis();
  } else {
    Debug.println("Failed to start AP mode!");
    // Try one more time after a longer delay
    delay(1000);
    if (WiFi.softAP(AP_SSID, AP_PASSWORD)) {
      Debug.println("AP mode started on retry");
      Debug.printf("AP IP address: %s\n", WiFi.softAPIP().toString().c_str());
      apMode = true;
      apStartTime = millis();
    } else {
      Debug.println("AP mode failed to start after retry!");
    }
  }
}

// WiFi reconnection state (non-blocking)
bool wifiReconnecting = false;
unsigned long wifiReconnectStartTime = 0;
const unsigned long WIFI_RECONNECT_TIMEOUT = 30000;  // 30 seconds max

// Handle WiFi connection in main loop (NON-BLOCKING)
void handleWiFi() {
  if (apMode) {
    // Check if we should exit AP mode after timeout
    if (millis() - apStartTime > AP_TIMEOUT) {
      Debug.println("AP mode timeout, attempting to reconnect to WiFi");
      // Stop AP before trying to reconnect
      WiFi.softAPdisconnect(true);
      delay(100);
      initWiFi();
    }
  } else {
    // Check if WiFi connection is lost
    if (WiFi.status() != WL_CONNECTED) {
      if (!wifiReconnecting) {
        // Start reconnection attempt
        Debug.printf("WiFi connection lost (status: %d), attempting to reconnect...\n", WiFi.status());
        
        // Use disconnect/begin instead of just reconnect()
        WiFi.disconnect(); 
        delay(100);
        WiFi.begin(ssid, password);
        
        wifiReconnecting = true;
        wifiReconnectStartTime = millis();
      } else {
        // Already reconnecting - check if we've timed out
        if (millis() - wifiReconnectStartTime > WIFI_RECONNECT_TIMEOUT) {
          Debug.printf("\nFailed to reconnect after %lu seconds (status: %d), starting AP mode\n",
                       WIFI_RECONNECT_TIMEOUT / 1000, WiFi.status());
          wifiReconnecting = false;
          startAPMode();
        }
        // Otherwise, just let the reconnection continue in the background
        // WiFi.reconnect() works asynchronously - no need to block
      }
    } else {
      // WiFi is connected
      if (wifiReconnecting) {
        Debug.println("WiFi reconnected successfully!");
        Debug.printf("IP address: %s\n", WiFi.localIP().toString().c_str());
        wifiReconnecting = false;
      }
    }
  }
}

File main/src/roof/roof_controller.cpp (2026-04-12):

/*
 * ESP32-S3 ASCOM Alpaca Roll-Off Roof Controller (v3)
 * Roof Controller Implementation
 */

#include "roof_controller.h"
#include "../mqtt/mqtt_handler.h"
#include "../sensors/park_sensor_udp.h"
#include "../safety/safety_sensor.h"
#include "../debug/Debug.h"
#include <Arduino.h>

// Define the global variables declared as extern in config.h
int LIMIT_SWITCH_OPEN_PIN = DEFAULT_OPEN_SWITCH_PIN;    // Default to pin 35
int LIMIT_SWITCH_CLOSED_PIN = DEFAULT_CLOSED_SWITCH_PIN; // Default to pin 36
int TRIGGERED = DEFAULT_TRIGGER_STATE;                  // Default to LOW trigger state
int TELESCOPE_PARKED = DEFAULT_PARK_STATE;              // Park sensor is HIGH until triggered
unsigned long movementTimeout = DEFAULT_MOVEMENT_TIMEOUT; // Movement timeout in ms
bool movementTimeoutEnabled = DEFAULT_TIMEOUT_ENABLED;  // Timeout monitoring enabled (default: true)
unsigned long limitSwitchTimeout = DEFAULT_LIMIT_SWITCH_TIMEOUT; // Limit switch change timeout (default: 5 seconds)
bool limitSwitchTimeoutEnabled = DEFAULT_LIMIT_SWITCH_TIMEOUT_ENABLED; // Limit switch timeout monitoring enabled (default: true)
unsigned long inverterDelay1 = DEFAULT_INVERTER_DELAY1; // Delay between K1 and K3 (default: 750ms)
unsigned long inverterDelay2 = DEFAULT_INVERTER_DELAY2; // Delay between inverter power-on and K2 (default: 1500ms)

// Limit switch states
bool lastOpenSwitchState = false;
bool lastClosedSwitchState = false;
bool bypassParkSensor = false;
bool lastTelescopeParkedState = false;
unsigned long lastTelescopeParkedStateTime = 0;
bool telescopeParked = false;
unsigned long lastOpenStateTime = 0;
unsigned long lastClosedStateTime = 0;

// Current device state
RoofStatus roofStatus = ROOF_CLOSED;
RoofStatus lastPublishedStatus = ROOF_CLOSED;   // Track last published status for change detection
bool slaved = false;
bool isConnected = true;                        // Device is always connected in this implementation
bool swapLimitSwitches = false;                 // Flag for swapping limit switch pins

// Error tracking for ASCOM compliance (error reason for Slewing exception)
String roofErrorReason = "";

// Timestamps for various operations
unsigned long lastSwitchTime = 0;
unsigned long movementStartTime = 0;

// Non-blocking state machine variables
RoofOperationState roofOpState = OP_IDLE;
RoofOperationTarget roofOpTarget = TARGET_NONE;
unsigned long roofOpStepStartTime = 0;
bool roofOpNeedsInverterButton = false;

// Inverter power state variables (NEW in v3)
bool inverterRelayState = false;                // State of K1 (12V power relay)
bool inverterACPowerState = false;              // State of AC power (detected via optocoupler)
bool lastInverterACPowerState = false;          // Last AC power state for change detection
unsigned long lastInverterACPowerChangeTime = 0;
bool inverterRelayEnabled = true;               // Enable K1 power relay control for roof movement (default: enabled)
bool inverterSoftPwrEnabled = true;             // Enable K3 soft-power button control for roof movement (default: enabled)

// Apply pin settings - useful after changing pin assignments or trigger state
void applyPinSettings() {
  // Configure input pins with internal pull-ups
  pinMode(TELESCOPE_PARKED_PIN, INPUT);
  pinMode(LIMIT_SWITCH_OPEN_PIN, INPUT_PULLUP);
  pinMode(LIMIT_SWITCH_CLOSED_PIN, INPUT_PULLUP);
  
  Debug.println("Pin settings applied:");
  Debug.print("TELESCOPE_PARKED_PIN: "); Debug.println(TELESCOPE_PARKED_PIN);
  Debug.print("LIMIT_SWITCH_OPEN_PIN: "); Debug.println(LIMIT_SWITCH_OPEN_PIN);
  Debug.print("LIMIT_SWITCH_CLOSED_PIN: "); Debug.println(LIMIT_SWITCH_CLOSED_PIN);
  Debug.print("TRIGGERED state: "); Debug.println(TRIGGERED == HIGH ? "HIGH" : "LOW");
  Debug.print("TELESCOPE_PARKED state: "); Debug.println(TELESCOPE_PARKED == HIGH ? "HIGH" : "LOW");
  
  // Immediately read and report the state of the telescope park pin
  int parkPinValue = digitalRead(TELESCOPE_PARKED_PIN);
  bool isParked = (parkPinValue == TELESCOPE_PARKED);
  Debug.print("Current TELESCOPE_PARKED_PIN value: "); Debug.println(parkPinValue);
  Debug.print("Telescope is currently interpreted as: "); Debug.println(isParked ? "PARKED" : "NOT PARKED");
}

void initializeRoofController() {
  // Initialize GPIO pins

  // Configure power inverter relay (K1)
  pinMode(INVERTER_PIN, OUTPUT);
  digitalWrite(INVERTER_PIN, LOW);  // Start with inverter OFF
  inverterRelayState = false;

  // Configure roof control button relay (K2)
  pinMode(ROOF_CONTROL_PIN, OUTPUT);
  digitalWrite(ROOF_CONTROL_PIN, LOW);  // Start with button NOT pressed

  // Configure inverter soft-power button relay (K3) - NEW in v3
  pinMode(INVERTER_BUTTON_PIN, OUTPUT);
  digitalWrite(INVERTER_BUTTON_PIN, LOW);  // Start with button NOT pressed

  // Configure AC power detection input - NEW in v3
  pinMode(INVERTER_AC_POWER_PIN, INPUT);
  inverterACPowerState = (digitalRead(INVERTER_AC_POWER_PIN) == LOW);
  lastInverterACPowerState = inverterACPowerState;
  lastInverterACPowerChangeTime = millis() - SWITCH_STABLE_TIME - 1;

  // Apply pin settings
  applyPinSettings();

  // Print initial pin states for debugging
  Debug.println("Initial pin states:");
  Debug.print("INVERTER_PIN (K1): "); Debug.println(digitalRead(INVERTER_PIN));
  Debug.print("ROOF_CONTROL_PIN (K2): "); Debug.println(digitalRead(ROOF_CONTROL_PIN));
  Debug.print("INVERTER_BUTTON_PIN (K3): "); Debug.println(digitalRead(INVERTER_BUTTON_PIN));
  Debug.print("INVERTER_AC_POWER_PIN: "); Debug.println(digitalRead(INVERTER_AC_POWER_PIN));
  Debug.print("TELESCOPE_PARKED_PIN: "); Debug.println(digitalRead(TELESCOPE_PARKED_PIN));
  Debug.print("LIMIT_SWITCH_OPEN_PIN: "); Debug.println(digitalRead(LIMIT_SWITCH_OPEN_PIN));
  Debug.print("LIMIT_SWITCH_CLOSED_PIN: "); Debug.println(digitalRead(LIMIT_SWITCH_CLOSED_PIN));
  Debug.print("Trigger state: "); Debug.println(TRIGGERED == HIGH ? "HIGH" : "LOW");
  Debug.print("Switches swapped: "); Debug.println(swapLimitSwitches ? "YES" : "NO");

  // Allow time for the pull-up resistors to fully settle
  delay(50);

  // Initialize status variables for debouncing
  lastOpenSwitchState = (digitalRead(LIMIT_SWITCH_OPEN_PIN) == TRIGGERED);
  lastClosedSwitchState = (digitalRead(LIMIT_SWITCH_CLOSED_PIN) == TRIGGERED);
  lastOpenStateTime = millis() - SWITCH_STABLE_TIME - 1; // Make initial reading valid immediately
  lastClosedStateTime = millis() - SWITCH_STABLE_TIME - 1;

  // Initialize telescope park state
  lastTelescopeParkedStateTime = millis() - SWITCH_STABLE_TIME - 1; // Make initial reading valid immediately
  updateTelescopeStatus();

  // Explicitly check initial roof status based on limit switches with extra care
  determineInitialRoofStatus();
}
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

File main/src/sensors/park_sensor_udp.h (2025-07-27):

/*
 * ESP32 ASCOM Alpaca Roll-Off Roof Controller
 * UDP Park Sensor Handler Header
 */

#ifndef PARK_SENSOR_UDP_H
#define PARK_SENSOR_UDP_H

#include <WiFiUdp.h>
#include <ArduinoJson.h>
#include <map>
#include <vector>
#include "config.h"

// UDP Park Sensor Configuration
#define PARK_SENSOR_UDP_PORT 23435
#define PARK_SENSOR_TIMEOUT 30000  // 30 seconds timeout
#define MAX_PARK_SENSORS 10        // Maximum number of sensors to track

// Park Sensor Status
enum ParkSensorStatus {
  SENSOR_UNKNOWN = 0,    // Never seen or timed out
  SENSOR_PARKED = 1,     // Safe to move (isSafeToMove = true)
  SENSOR_UNPARKED = 2,   // Not safe to move (isSafeToMove = false)
  SENSOR_OFFLINE = 3     // Sensor has timed out
};

// Park Sensor Data Structure
struct ParkSensor {
  String uuid;
  String deviceType;
  String serialNumber;
  String ipAddress;
  String name;
  float pitch;
  float roll;
  bool isSafeToMove;
  ParkSensorStatus status;
  unsigned long lastSeen;
  bool enabled;          // Whether this sensor is enabled for park checking
  bool bypassEnabled;    // Individual bypass for this sensor
  
  // Constructor
  ParkSensor() : 
    pitch(0.0), roll(0.0), isSafeToMove(false), 
    status(SENSOR_UNKNOWN), lastSeen(0), 
    enabled(false), bypassEnabled(false) {}
};

// Park Sensor Type Selection
enum ParkSensorType {
  PARK_SENSOR_PHYSICAL = 0,  // Use physical park sensor circuit
  PARK_SENSOR_UDP = 1,       // Use UDP-based park sensors
  PARK_SENSOR_BOTH = 2       // Use both (AND logic - all must be parked)
};

// Global variables
extern WiFiUDP parkSensorUdp;
extern std::map<String, ParkSensor> discoveredSensors;
extern std::vector<String> enabledSensorUuids;
extern ParkSensorType parkSensorType;
extern bool udpParkSensorSystemEnabled;

// Function prototypes
void initParkSensorUDP();
void handleParkSensorUDP();
void processParkSensorMessage(const String& message, IPAddress remoteIP);
void updateParkSensorStatus();
bool isTelescopeParkedUDP();
void addParkSensor(const String& uuid);
void removeParkSensor(const String& uuid);
void removeAllParkSensors();
void setParkSensorBypass(const String& uuid, bool bypassed);
void setParkSensorEnabled(const String& uuid, bool enabled);
String getParkSensorStatusString(ParkSensorStatus status);
void saveParkSensorConfiguration();
void loadParkSensorConfiguration();
void clearTimeoutSensors();
std::vector<ParkSensor> getActiveSensors();
std::vector<ParkSensor> getDiscoveredSensors();

#endif // PARK_SENSOR_UDP_H

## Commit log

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2026-01-10 Add Roof Control page and configurable movement timeout
    FEATURES ADDED:
    1. New Roof Control page (/control)
    - Dedicated page for roof and inverter control
    - Real-time status display (roof, park sensor, limit switches, inverter states)
    - Roof movement buttons (Open, Stop, Close)
    - Inverter control buttons (Toggle K1, Press K3)
    - Removed confirmation dialogs for faster operation
    2. Configurable Movement Timeout
    - Added timeout setting to Setup page (10-600 seconds)
    - Stored in preferences, persists across reboots
    - Default: 90 seconds
    - Accessible via web UI
    3. Web API Endpoints
    - POST /control - Displays roof control page
    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
    [config.h, html_templates.h, roof_controller.cpp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]
2026-01-10 Add MQTT Client ID configuration and park sensor debug logging
    MQTT Configuration:
    - Add MQTT Client ID input field to web UI setup page
    - Update saveConfiguration() to persist MQTT Client ID
    - Update handleSetupPost() to process MQTT Client ID changes
    - Users can now customize MQTT Client ID to prevent conflicts between multiple controllers
    Park Sensor Debug Logging:
    - Add comprehensive debug logging to startOpeningRoof() and startClosingRoof()
    - Log bypassParkSensor state, telescopeParked state, and park sensor type
    - Add clear safety check pass/fail messages
    - Helps diagnose why roof moves when telescope shows unparked
    This addresses the issue where testing multiple controllers caused c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
    [config.h, html_templates.h, mqtt_handler.cpp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]
2026-01-10 Make MQTT topics unique by default and add single roof control button
    MQTT Topic Uniqueness:
    - Append chip ID to MQTT topic prefix by default (similar to client ID)
    - Only appends if topic is still default or doesn't contain underscore
    - Prevents conflicts when multiple controllers are on same network
    - Users can still customize topic prefix manually in web UI
    - Topics now auto-generated as "observatory/roof_<chipID>/status", etc.
    Single Roof Control Button:
    - Replace three separate Open/Stop/Close buttons with single button
    - Button mimics physical button behavior (cycles through states)
    - Context-aware labeling: "OPEN ROOF" (green), "CLOSE ROOF" (blue), "STOP" (red)
    - Logic: If moving ->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
    [html_templates.h, mqtt_handler.cpp, web_ui_handler.cpp]
2026-01-10 Add static button label and real-time status updates
    Static Roof Control Button:
    - Change button label from dynamic to static "ROOF CONTROL"
    - Use consistent blue color instead of state-dependent colors
    - Avoids confusion during error states or manual control
    - Button behavior remains the same (context-aware)
    Real-Time Status Updates:
    - Add /api/status endpoint returning JSON status
    - Implement JavaScript polling every 2 seconds
    - Update all status indicators without page reload
    - Updates: roof status, telescope parked, bypass, limit switches, inverter states
    - Remove page reloads from button actions (smoother UX)
    - Add "auto-updates every 2 seconds" text to status header
    - Add IDs to all s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
    [html_templates.h, web_ui_handler.cpp]
2026-01-10 Add bypass toggle, simplify roof button, and add real-time home page updates
    Roof Control Page Improvements:
    - Add bypass toggle directly on Roof Control page
    - Allows users to enable/disable park sensor bypass for manual control
    - Toggle state updates in real-time via API polling
    - Relabel button from "ROOF CONTROL" to "OPEN / CLOSE"
    Simplified Roof Button Logic:
    - Roof button now mimics physical button exactly
    - Just sends button press via sendButtonPress() - no limit switch checks
    - Only checks park sensor state (unless bypass is enabled)
    - Removes timeout issues caused by limit switch state checks
    - Hardware controller handles all the open/close/stop logic
    Real-Time Status Updates on H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
    [html_templates.h, web_ui_handler.cpp]
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2026-01-10 Fix white backgrounds and text colors for consistent dark theme
    - Changed all light backgrounds (#f9f9f9, #f0f0f0, #f8f9fa) to dark (#2d2d2d)
    - Updated dark gray text (#666) to lighter shade (#b0b0b0) for better readability
    - Fixed navigation bar, bypass toggle, timing settings, and help text colors
    - All pages now have consistent dark theme formatting matching main landing page
    [html_templates.h]
2026-01-10 Implement consistent page layouts and improve text contrast
    - Added status header to Roof Control and Setup pages matching home page
    - Replaced old navbar with larger nav-button style navigation on all pages
    - Fixed light grey text in bypass toggle section for better readability
    - All pages now have consistent header, status bar, and navigation layout
    [html_templates.h]
2026-01-11 Add inverter auto-power control and fix page layouts
    Layout improvements:
    - Removed 'Home' button from navigation on Roof Control and Setup pages
    - Consistent navigation matches home page style
    Inverter auto-power feature:
    - Added configurable inverter auto-power setting (enabled by default)
    - When enabled, automatically powers inverter and sends soft-power button when opening/closing roof
    - Sequence: Turn on K1 → wait 750ms → check AC power on GPIO7 → send K3 if needed → send K2
    - Only controls inverter if auto-power is enabled, allowing users to disable for setups without inverters
    - Added toggle switch in Device Setup page under new "Inverter Settings" section
    - Setting is persis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
    [config.h, html_templates.h, roof_controller.cpp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]
2026-01-11 Fix page layouts and header styles to match home page
    - Added proper page headers with title and version to Roof Control and Setup pages
    - Added inline styles for status-header, nav-button, and status-card to match home page
    - Navigation buttons now have large, readable size (10px 20px padding)
    - Status header has proper 24px font size with colored background
    - All pages now have consistent layout: Page Title → Status Bar → Navigation → Content
    [html_templates.h]
2026-01-11 Add separate controls for inverter relay and soft-power button
    - Split single inverter auto-power toggle into two independent controls:
    * Enable Power Relay (K1) - controls 12V power to inverter
    * Enable Soft-Power Button (K3) - controls soft-power button press
    - Users can now enable/disable relay and soft-power independently
    - Updated timing sequence:
    * If relay enabled: Turn on K1 → wait 750ms
    * If soft-power enabled: Check AC power, send K3 if needed → wait 1500ms
    * Send K2 roof button
    - Delays are skipped when features are disabled
    - Added 1.5 second delay after soft-power button press (as requested)
    - Both settings persist across reboots
    - Setup page shows both toggles wit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
    [config.h, html_templates.h, roof_controller.cpp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]
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2026-01-11 Fix park sensor type radio button layout
    - Restructured radio buttons to display vertically with labels to the right
    - Each option is now on its own row with 10px spacing
    - Buttons are left-aligned to each other
    - Entire group is centered on the page
    - Labels are 8px to the right of their buttons
    [html_templates.h]
2026-01-11 Fix radio button and label to display on same line
    - Added display: flex and align-items: center to each radio button row
    - This places the label to the right of the radio button on the same line
    - Added cursor: pointer to labels for better UX
    - Buttons remain left-aligned and centered on page
    [html_templates.h]
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2026-01-11 Swap button order and enable OPEN/CLOSE button permanently
    - Moved OPEN/CLOSE button to the left, START/STOP to the right
    - Removed disabled state from OPEN/CLOSE button
    - OPEN/CLOSE button always enabled since it has built-in safety checks in handler
    [html_templates.h]
2026-01-11 Fix header status not updating on Roof Control and Device Setup pages
    - Added header status update code to Roof Control page updateStatus() function
    - Added status update polling to Device Setup page (was missing entirely)
    - Both pages now update mainStatusHeader, mainStatusIndicator, and mainStatusText
    - Header status will now stay in sync with actual roof status on all pages
    [html_templates.h]
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2026-01-11 Add configurable movement timeout monitoring
    - Added movementTimeoutEnabled setting to enable/disable timeout monitoring
    - Updated checkMovementTimeout() to skip if monitoring is disabled
    - Added UI toggle on Device Setup page for enabling/disabling monitoring
    - Movement timeout duration remains configurable (10-600 seconds)
    - Default behavior: monitoring enabled with 90 second timeout
    - Settings saved to preferences and persist across reboots
    - Updated Current Configuration display to show monitoring status
    [config.h, html_templates.h, roof_controller.cpp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]
2026-01-11 Add configurable limit switch timeout
    - Added limitSwitchTimeout setting (default: 5 seconds, range: 1-30 seconds)
    - This is the time to wait for limit switch state to change after movement starts
    - Distinguished from overall movement timeout (which checks full open/close within 90 seconds)
    - Updated updateRoofStatus() to use configurable limitSwitchTimeout instead of hardcoded 5000ms
    - Added UI input field on Device Setup page for limit switch timeout
    - Updated timeout description to clarify: Movement Timeout is for full open/close, Limit Switch Timeout is for switch state change
    - Updated Current Configuration display to show both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
    [config.h, html_templates.h, roof_controller.cpp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]
2026-01-11 Fix limit switch timeout not respecting enabled/disabled state
    - Modified updateRoofStatus() to skip limit switch timeout check when movementTimeoutEnabled is false
    - Previously only the 90-second movement timeout was being disabled
    - Now BOTH timeouts respect the movementTimeoutEnabled flag
    - When disabled, roof responds only to actual limit switch states, not time-based checks
    - Fixes issue where inverter was being turned off after limit switch timeout even when monitoring was disabled
    [roof_controller.cpp]
2026-01-11 Fix inverter shutoff when movement timeout monitoring is disabled
    - When monitoring is disabled, only turn off inverter if roof genuinely reached a limit
    - Check if roof was OPENING before turning off at OPEN limit
    - Check if roof was CLOSING before turning off at CLOSED limit
    - Prevents premature shutoff when roof hasn't moved from starting position
    - Limit switch timeout delay still applies (to give roof time to start moving)
    - But automatic shutoff after timeout only occurs when monitoring is enabled
    [roof_controller.cpp]
2026-01-11 Add separate enable/disable toggle for limit switch timeout monitoring
    - Added limitSwitchTimeoutEnabled flag to independently control limit switch timeout monitoring
    - Separated from movementTimeoutEnabled so both can be controlled independently
    - Limit switch timeout: Turns off inverter if switch doesn't change within 5 seconds (configurable)
    - Movement timeout: Turns off inverter if roof doesn't fully open/close within 90 seconds (configurable)
    - Both timeouts now have separate enable/disable toggles on Device Setup page
    - Reordered UI to show limit switch timeout first, then movement timeout
    - Updated descriptions to clarify: "Monitor Limit Switch Changes" vs "Monitor Total Movement Time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
    [config.h, html_templates.h, roof_controller.cpp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]
2026-01-11 Fix movement timeout not triggering when limit switch monitoring disabled
    - When limit switch timeout monitoring is disabled, keep status in OPENING/CLOSING
    - Don't revert to OPEN/CLOSED just because original limit switch is still triggered
    - This allows movement timeout to trigger even when roof hasn't physically moved yet
    - Previous bug: status changed back to OPEN/CLOSED after limit switch timeout,
    preventing movement timeout from ever firing (only checks OPENING/CLOSING states)
    - Now movement timeout will properly trigger after configured time period
    [roof_controller.cpp]
2026-01-11 Fix movement timeout by checking correct moving state
    - When open limit triggered, check if status is CLOSING (not OPENING)
    - When closed limit triggered, check if status is OPENING (not CLOSING)
    - Previous fix had the logic backwards - was checking wrong moving state
    - Now correctly keeps status in moving state when limit switch monitoring disabled
    - This allows movement timeout to properly trigger after configured time
    [roof_controller.cpp]
2026-01-11 Center timing settings toggles to align with timeout inputs
    - Wrapped limit switch timeout toggle in centered flex container
    - Wrapped movement timeout toggle in centered flex container
    - Both toggles now horizontally centered on page to match timeout input boxes
    - Improves visual consistency and alignment of timing settings section
    [html_templates.h]
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2026-01-16 Delete PCB Files directory
    Removed gerbers due to error in layout for K1, K2 and K3 relays. Will reupload with corrections following additional testing.
    [BOM_Board_v3.0_Schematic_v3.0.xlsx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]
2026-01-16 Invert IO7/IO42 logic and add park switch type toggle
    - Invert IO7 (AC power detection): With 12V applied to optocoupler,
    pin is pulled LOW, so AC power present = LOW (was incorrectly HIGH)
    - Invert IO42 (park state) default: Normally open switch pulls pin
    LOW when parked, changed DEFAULT_PARK_STATE from HIGH to LOW
    - Add configurable toggle on setup page to switch between normally
    open (LOW when parked) and normally closed (HIGH when parked)
    switch types, with preference storage for persistence
    [config.h, html_templates.h, roof_controller.cpp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]
2026-01-16 Add factory reset and fix WiFi/AP mode transitions
    - Add factory reset button and endpoint (/factory_reset) that clears
    all saved preferences and restarts the device in AP mode
    - Fix WiFi/AP mode transitions by properly cleaning up WiFi state
    before switching modes (disconnect, delays, etc.)
    - Detect placeholder SSID "YOUR_SSID" and go directly to AP mode
    - Add retry mechanism for AP mode startup
    - Add WiFi status codes to debug output for better diagnostics
    - Stop AP properly before attempting WiFi reconnection after timeout
    This fixes the issue where AP mode may not start correctly when
    WiFi credentials are invalid or the network is unavailable.
    [html_templates.h, main.ino, web_ui_handler.cpp]
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2026-01-26 Add ASCOM-compliant error reporting on Slewing property
    Per ASCOM standards, when an async shutter operation fails (e.g., timeout),
    the Slewing property must raise an exception with a descriptive error
    message. Previously, ShutterStatus returned shutterError but Slewing
    just returned false, giving clients no information about what went wrong.
    Changes:
    - Add roofErrorReason global to track error cause
    - Set descriptive error messages for:
    - Movement timeout (limit switch didn't trigger in time)
    - Both limit switches triggered (hardware fault)
    - Unknown position at startup (neither switch triggered)
    - handleSlewing() now returns error 0x500 (DriverException) with
    the error reason when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
    [alpaca_handler.cpp, roof_controller.cpp]
2026-01-26 Add debug logging to Slewing handler for ASCOM conformance troubleshooting
    Logs the response being returned (true, false, or error) to help
    diagnose NINA's "did not report shutter movement or failure" warning.
    [alpaca_handler.cpp]
2026-01-26 Fix race condition in timeout error reporting for ASCOM compliance
    When a movement timeout occurred, there was a race condition:
    1. stopRoofMovement() was called first
    2. stopRoofMovement() called updateRoofStatus()
    3. updateRoofStatus() set roofStatus = ROOF_CLOSED (based on limit switch)
    4. RACE WINDOW: ASCOM client polling Slewing sees false (not exception)
    5. Then roofStatus = ROOF_ERROR was set
    This caused NINA to report "Dome did not report shutter movement or
    failure after completing the request" because Slewing went from true
    to false without an exception, even though the operation failed.
    Fix:
    - Set roofStatus = ROOF_ERROR BEFORE calling stopRoofMovement()
    - Add updateStatus param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
    [roof_controller.cpp]
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2026-01-26 Fix: Don't revert moving state when source limit switch still triggered
    When trying to close from open (or open from closed), if the source
    limit switch is still triggered after the limitSwitchTimeout, the code
    was reverting to the source state (ROOF_OPEN/ROOF_CLOSED). This prevented
    the movement timeout from ever firing, causing NINA to see Slewing go
    from true to false without an exception.
    New logic:
    - If ROOF_CLOSING and open switch triggered: stay ROOF_CLOSING
    - If ROOF_OPENING and closed switch triggered: stay ROOF_OPENING
    - Only transition to destination state on success (reaching other limit)
    - Movement timeout will set ROOF_ERROR if roof doesn't actually move
    [roof_controller.cpp]
2026-01-26 Add immediate error when roof fails to start moving
    Two distinct error conditions now:
    1. Fails to START (after limitSwitchTimeout, default 5 sec):
    Source limit switch still triggered after timeout = roof didn't move
    → Immediate ROOF_ERROR with descriptive message
    2. Fails to COMPLETE (after movementTimeout, default 90 sec):
    Roof left source but didn't reach destination in time
    → ROOF_ERROR after full timeout
    Both timeouts are configurable at runtime via web UI.
    [roof_controller.cpp]
2026-01-26 Fix: Make ROOF_ERROR state sticky - don't auto-clear on limit switch
    When handleShutterStatus() called updateRoofStatus(), the error state
    was being overwritten because the code saw a limit switch triggered
    and transitioned to ROOF_OPEN/ROOF_CLOSED.
    Now ROOF_ERROR is preserved until explicitly cleared by:
    - clearRoofError() function
    - Starting a new movement operation (which clears roofErrorReason)
    This ensures ShutterStatus correctly reports Error (4) after a failure.
    [roof_controller.cpp]
2026-01-26 Add Clear Error button to web UI
    - Button appears in Roof Control section only when in ERROR state
    - Calls clearRoofError() to reset state and re-check limit switches
    - New endpoint: POST /clear_error
    [html_templates.h, web_ui_handler.cpp]
2026-01-26 Update to v3.1.0, fix Clear Error button dynamic visibility
    - Bump version to 3.1.0
    - Add TODO note for future NTP/RTC independence when RTC support is added
    - Fix Clear Error button to appear dynamically without page refresh when
    controller enters error state (button now always rendered, visibility
    controlled via JavaScript in updateStatus())
    [config.h, html_templates.h]
2026-01-26 Add DS3231 RTC support, decouple NTP from GPS dependency
    - Add I2C pins (SDA=GPIO8, SCL=GPIO9) and DS3231 RTC support
    - RTC provides backup time when GPS has no fix
    - RTC automatically syncs from GPS on first valid fix
    - NTP server now works with either GPS or RTC time source
    - NTP reference ID shows "GPS" or "LOCL" based on time source
    - Add GPS latitude/longitude to home page status card
    - Add time source and RTC status to WebUI displays
    [config.h, gps_handler.cpp, html_templates.h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]
2026-01-26 Make GPS TX/RX/PPS pins user-configurable via WebUI
    - GPS TX pin (receives data from GPS) - required, default GPIO14
    - GPS RX pin (send commands to GPS) - optional, default -1 (disabled)
    - GPS PPS pin (pulse-per-second timing) - optional, default -1 (disabled)
    - Pin settings saved to preferences and persist across reboots
    - Changes require device restart to take effect
    - Added pin configuration UI in GPS/RTC setup card
    [config.h, gps_handler.cpp, html_templates.h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]
2026-01-26 Improve park sensor bypass font visibility and enhance GPS status display
    - Change park sensor bypass label color from grey (#e0e0e0) to white (#ffffff)
    when disabled, maintaining red (#e57373) for enabled/bypassed state
    - Add satellites in view count from GSV sentences, display as "X / Y" format
    where X is satellites used in fix and Y is satellites in view
    - Add HDOP (horizontal dilution of precision) parsing from GGA sentences
    and display accuracy on GPS Fix line when available
    - Add altitude row to GPS status card below Longitude
    - Update API endpoints to include new GPS fields (satellites_in_view, hdop, altitude)
    https://claude.ai/code/session_01W2QyMUziikk9uFr65VEYwt
    [gps_handler.cpp, html_templates.h, web_ui_handler.cpp]
2026-01-26 Display error reason in parentheses after Error status on WebUI
    - Add error_reason field to /api/status JSON response
    - Update all JavaScript updateStatus() functions to display error reason
    when status is 'Error' and error_reason is available
    - Update initial HTML rendering on Home, Device Setup, and Roof Control
    pages to show error reason in the status header and status table
    - Format: "Error (Roof movement timed out after 90 seconds.)"
    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
    [html_templates.h, web_ui_handler.cpp]
2026-01-26 Fix bypass label color and add timeout error guidance
    - Fix park sensor bypass label color reverting to grey (#333) on status
    updates - now correctly uses white (#ffffff) when disabled across all
    JavaScript dynamic updates
    - Add popup warning when clearing error with neither limit switch triggered,
    advising user to manually move roof to a known position first
    - Show brief "Timeout - manual intervention required" message instead of
    full error text when movement times out with no limit switches triggered
    - Update both JavaScript dynamic updates and initial HTML rendering
    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
    [html_templates.h]
2026-01-26 Change GPS HDOP display to accuracy in meters and fix satellites display
    - Convert HDOP to approximate accuracy in meters using formula:
    accuracy = HDOP × 2.5m (typical civilian GPS base accuracy)
    - Display format changed from "(HDOP: 1.1)" to "(Accuracy: +/- 2.8m)"
    - Fix satellites display when GSV sentences not available:
    Shows just "8" instead of "8 / 0" when satellites_in_view is zero
    - GSV sentences are optional and some GPS modules don't output them
    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
    [html_templates.h]
2026-01-26 Improve timeout error message with actionable guidance
    Replace brief "Timeout - manual intervention required" with more
    descriptive single-line message that explains the problem and solution:
    "Timeout: Roof stopped mid-travel. Manually move to fully open or closed, then clear error."
    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
    [html_templates.h]
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2026-01-28 Refactor roof operations to non-blocking state machine
    Replace blocking delay() calls in startOpeningRoof(), startClosingRoof(),
    and stopRoofMovement() with a non-blocking state machine. This prevents
    WiFi/MQTT from becoming unresponsive during roof operations.
    Previously, the relay timing sequences used delay() calls totaling
    750-2000ms, which blocked the main loop and caused the controller to
    briefly become unavailable to Home Assistant.
    The new processRoofOperation() function runs in the main loop and
    advances through relay states using millis() timing, allowing WiFi
    and MQTT to continue operating normally.
    Rollback: git checkout pre-nonblocking-refactor
    https://claude.ai/code/session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
    [main.ino, roof_controller.cpp]
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
